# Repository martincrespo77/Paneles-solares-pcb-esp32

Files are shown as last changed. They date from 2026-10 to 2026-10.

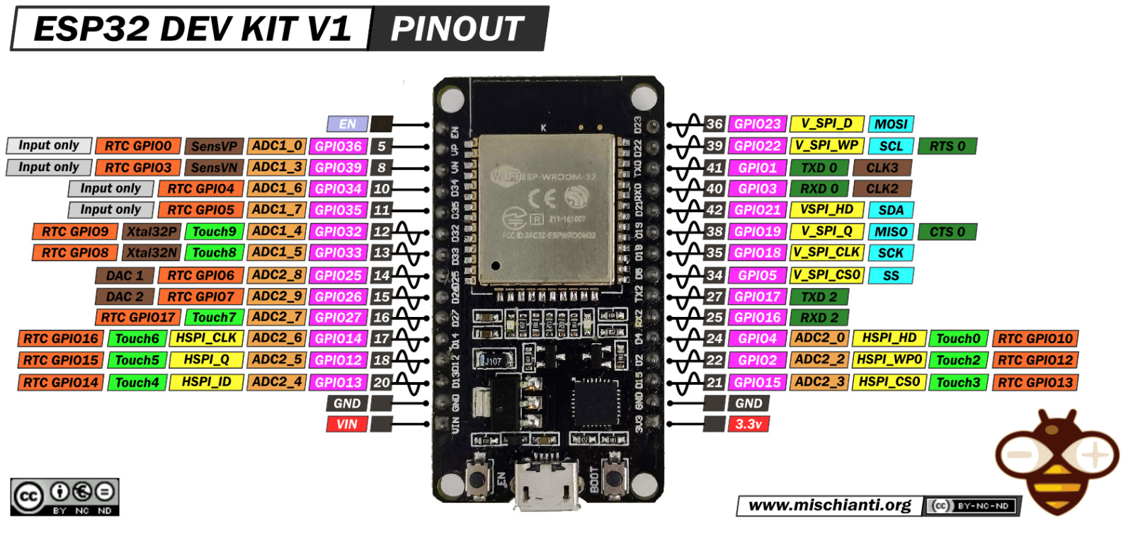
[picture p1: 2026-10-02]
Esp32 para diagrama digital.jpeg

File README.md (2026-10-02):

# Seguidor Solar (Sun Tracker) de 2 Ejes con ESP32

**Cátedra:** Técnicas Digitales 2 — FIE (Facultad de Ingeniería del Ejército)  
**Estado:** Firmware base implementado y verificado en PlatformIO  

---

## 1. Descripción del Proyecto

Este proyecto consiste en la **migración y modernización del sistema de control del Seguidor Solar (Sun Tracker) de dos ejes** (Azimut y Elevación). 

El sistema original estaba implementado en código de bajo nivel en C para un microcontrolador AVR (**ATmega168/328**) utilizando el puente H L298HN y un demultiplexor CD4053 (referencia: informe técnico `UNDEFI 263` en `INFORMACION VIEJA/`).

En esta etapa se porta el núcleo de control hacia un microcontrolador moderno **ESP32 DOIT DevKit V1 (30 pines)** bajo el framework PlatformIO / Arduino C++, conservando las ecuaciones físicas del lazo de control, la calibración PI probada y la robustez del accionamiento.

---

## 2. Arquitectura de Control

```
                 [ 4 LDRs en cruz: F0, F1, F2, F3 ]
                                |
                                v
               [ ADC1 del ESP32 (4 canales a 10 bits) ]
                                |
                                v
                [ Cálculo de error (Azimut / Elevación) ]
                                |
                                v
             [ Control PI por eje con Anti-Windup y Deadband ]
                                |
                                v
            [ Generación PWM (LEDC 1 kHz) + Señales de Sentido ]
                                |
                                v
                [ Etapa de Potencia: Puente H Doble ]
                                |
                                v
              [ Motores DC Azimut (P1) y Elevación (P2) ]
```

### Algoritmo y Ley de Control

1. **Lectura ADC:** Lee los 4 sensores LDR sobre el ADC1 (evitando conflictos de Wi-Fi), aplicando promediado de 8 muestras y reescalado de 12 a 10 bits (`0..1023`) para mantener compatibilidad con las constantes legadas.
2. **Cálculo de Error:**
   - Elevación: `Error_El = (F2 + F3 - F0 - F1) / 2`
   - Azimut: `Error_Az = (F1 + F3 - F0 - F2) / 2`
3. **Controlador PI Discreto:**
   - Ganancias: $K_p = 5.0$, $K_i = 0.1$, $K_d = 0.0$
   - Límite Anti-Windup: Clamping del integrador a $\pm 400.0$
   - Zona Muerta (`DEAD_BAND = 5`): Evita oscilaciones por jitter o ruido eléctrico cuando el panel está orientado.
4. **Modulación PWM:** Canales LEDC a 1 kHz con 10 bits de resolución (`PWM_MAX = 1023`).

---

## 3. Mapeo de Pines (ESP32 DevKit V1)

| Señal | Pin ESP32 | Función | Destino en Hardware |
|---|:---:|---|---|
| **FOTO0** | `GPIO36` (VP) | Entrada ADC1 Ch0 | LDR 0 (Superior izquierdo) |
| **FOTO1** | `GPIO39` (VN) | Entrada ADC1 Ch3 | LDR 1 (Superior derecho) |
| **FOTO2** | `GPIO34` | Entrada ADC1 Ch6 | LDR 2 (Inferior izquierdo) |
| **FOTO3** | `GPIO35` | Entrada ADC1 Ch7 | LDR 3 (Inferior derecho) |
| **PWM_AZ** | `GPIO25` | Salida PWM (LEDC CH0) | ENA / Entrada PWM motor Azimut |
| **PWM_EL** | `GPIO26` | Salida PWM (LEDC CH1) | ENB / Entrada PWM motor Elevación |
| **DIR_AZ** | `GPIO27` | Salida Digital | IN_A / Sentido de giro Azimut |
| **DIR_EL** | `GPIO14` | Salida Digital | IN_B / Sentido de giro Elevación |
| **STATUS** | `GPIO2` | Salida Digital | LED onboard (Heartbeat / Fault) |

---

## 4. Estructura del Repositorio

*   [`src/main_tracker.cpp`](src/main_tracker.cpp): Firmware principal en C++ para la ESP32.
*   [`platformio.ini`](platformio.ini): Configuración de compilación para ESP32 DOIT DevKit V1.
*   [`Kicad/Control de panel/`](Kicad/Control%20de%20panel/): Proyecto de esquemático y PCB en KiCad adaptado para zócalo ESP32 DevKit V1 30 pines.
*   [`docs/`](docs/):
    *   [`CONTEXTO_TD2_SUN_TRACKER.md`](docs/CONTEXTO_TD2_SUN_TRACKER.md): Contexto técnico detallado y trazabilidad del proyecto.
    *   [`DOCUMENTO_TECNICO_TD2_SUN_TRACKER.md`](docs/DOCUMENTO_TECNICO_TD2_SUN_TRACKER.md): Especificación técnica formal y modelo matemático.
    *   [`PLANMODE_ARMADO_TD2.md`](docs/PLANMODE_ARMADO_TD2.md): Guía de validación y puesta en marcha en banco por etapas.
*   [`INFORMACION VIEJA/`](INFORMACION%20VIEJA/): Archivos históricos de referencia (informe final UNDEFI 263, esquemático analógico y firmware AVR en C).

---

## 5. Compilación y Carga

Con [PlatformIO](https://platformio.org/) instalado:

```powershell
# Compilar el firmware del Sun Tracker
pio run -e tracker

# Cargar a la placa ESP32 (ajustar puerto COM en platformio.ini si difiere)
pio run -e tracker -t upload

# Abrir el monitor serie (115200 baud)
pio device monitor -e tracker
```

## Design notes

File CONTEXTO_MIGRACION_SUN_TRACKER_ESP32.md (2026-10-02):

# Contexto tecnico del proyecto Sun Tracker y migracion a ESP32

Fecha de analisis: 2026-05-22

Este documento resume lo entendido del proyecto actual, del firmware viejo, del circuito general del informe y del objetivo de migracion. No es todavia un plan de implementacion. Sirve para validar si estamos hablando del mismo problema antes de pedir un plan detallado.

## 1. Resumen corto

El repositorio contiene dos lineas de trabajo relacionadas:

1. **Sun Tracker viejo**: sistema de seguimiento solar de dos ejes, azimut y elevacion, basado en un microcontrolador AVR ATmega168/328, cuatro sensores LDR, control PI/PID discreto y un puente H L298 para mover dos motores DC con reductor.
2. **Trabajo nuevo con ESP32**: primer material para usar ESP32 con MicroPython, medicion/telemetria de variables solares y transmision optica por laser. Ese codigo nuevo todavia no controla motores.

El objetivo actual es conservar la logica funcional del Sun Tracker viejo, migrarla a una **ESP32 programada en MicroPython/Python**, y mover los motores mediante un **puente H**. El enfoque correcto es portar primero el control de seguimiento y despues integrarlo con la telemetria optica, no mezclar todo desde el primer paso.

## 2. Archivos relevantes encontrados

### Material viejo

- `INFORMACION VIEJA-20260522T124344Z-3-001/INFORMACION VIEJA/UNDEFI 263 - Informe Final.pdf`
  - Informe tecnico del Sun Tracker.
  - Explica objetivo, mecanica, sensores, motores, puente H, PID discreto y circuito.

- `INFORMACION VIEJA-20260522T124344Z-3-001/INFORMACION VIEJA/Circuito Eléctrico/Sun_seeker.PDF`
  - Esquematico electronico general.
  - Incluye ATmega168/328, L298HN, CD4053, LM7805, sensores LDR y conectores de motores.

- `INFORMACION VIEJA-20260522T124344Z-3-001/INFORMACION VIEJA/Firmware/Sun Tracker/Sun Tracker/popo/popo/`
  - Firmware en C para AVR.
  - Archivos principales: `popo.c`, `ADC.c`, `Leo_Fotos.c`, `PWM.c`, `PID_Elev.c`, `PID_Azim.c`, `PORT.c`, `Constantes.c`, `USART.c`, `Def.h`.

### Material nuevo

- `Info general.md`
  - Define un sistema de telemetria solar por enlace optico FSO usando dos ESP32.
  - Usa sensor de energia, laser, fototransistor/comparador y tramas JSON con CRC.

- `Código de Ejecución en MicroPython (Nodo Transmisor).py`
  - Script MicroPython inicial para ESP32.
  - Lee valores simulados de energia, arma JSON, calcula CRC32 y transmite por UART hacia laser.
  - No controla LDR ni motores.

- `Diagrama de flujo.txt`
  - Flujo del nodo transmisor de telemetria: inicializar perifericos, leer sensor, acumular potencia, generar historico, armar JSON, calcular CRC y transmitir.

- `Proyecto FINAL Optoelectronica/`
  - Carpeta encontrada vacia.

- `Proyecto FINAL Tecnicas digitales 2/`
  - Carpeta encontrada vacia.

## 3. Que hace el proyecto viejo

El proyecto viejo es un **seguidor solar de doble eje**. Su objetivo es orientar un panel fotovoltaico hacia el Sol para mejorar la captacion de energia.

Segun el informe, el sistema tiene:

- Panel solar fotovoltaico Solartec KS45TA de 45 Wp.
- Movimiento en dos ejes:
  - **Azimut**.
  - **Elevacion**.
- Dos motores de corriente continua con reductor, modelo IGNIS MR08D-012004-4.0, con motor Mabuchi RS-385PH-2085.
- Sensado de luz mediante cuatro LDR ubicados en un discriminador de sombra en forma de cruz.
- Control digital ejecutado en un microcontrolador AVR.
- Accionamiento de motores mediante puente H L298.

La idea de control es tradicional y correcta para este tipo de prototipo: comparar luz recibida en cuatro cuadrantes, calcular error por eje, y mover cada motor hasta minimizar el error.

## 4. Sensores y calculo de error

El sensor optico viejo usa cuatro LDR:

- `FOTO0`
- `FOTO1`
- `FOTO2`
- `FOTO3`

Estan separados por una barrera horizontal y una barrera vertical. Esa cruz genera sombras cuando el panel no esta orientado correctamente.

El firmware viejo lee los cuatro sensores por ADC:

- `ADC0 -> FOTO0`
- `ADC1 -> FOTO1`
- `ADC2 -> FOTO2`
- `ADC3 -> FOTO3`

La logica de error implementada en C es:

```c
Error_El = (adc_dato_2 + adc_dato_3 - adc_dato_0 - adc_dato_1) / 2;
Error_Az = (adc_dato_1 + adc_dato_3 - adc_dato_0 - adc_dato_2) / 2;
```

Interpretacion:

- Elevacion compara el promedio inferior/superior, segun como esten montados los LDR.
- Azimut compara el promedio derecho/izquierdo.
- Si el error es positivo o negativo, cambia el sentido del motor.
- Si el error tiende a cero, el sistema esta alineado.

Esto hay que conservar en la migracion. Si se invierte fisicamente un motor o se cambia el orden de LDR, no se cambia la teoria: se ajusta el signo o el mapeo.

## 5. Circuito viejo segun informe y esquematico

El circuito viejo se organiza asi:

```text
4 LDR -> ADC0..ADC3 del ATmega -> calculo de error -> PI/PID discreto
      -> PWM + bits de sentido -> CD4053 / L298 -> motores DC de azimut y elevacion
```

Componentes principales:

- **U1: ATmega168/328**
  - El informe habla de ATmega328.
  - El proyecto Atmel Studio figura configurado como ATmega168.
  - El comentario del firmware dice que el codigo es compatible con ATmega328 y ATmega168.

- **U2: L298HN**
  - Puente H doble.
  - Maneja dos motores DC.
  - Un puente para azimut.
  - Otro puente para elevacion.

- **U3: CD4053BCN**
  - Multiplexor/demultiplexor analogico usado para direccionar senales de control hacia el L298.

- **U4: LM7805**
  - Regulador lineal para alimentar la electronica de control a 5 V.

- **D1 a D8: FR107**
  - Diodos rapidos de rueda libre para proteger frente a energia inductiva de los motores.

- **Y1: cristal de 16 MHz**
  - El esquematico muestra 16 MHz.

- **R2, R3, R4, R5: 4k7**
  - Resistencias asociadas a los sensores LDR.

- **P1**
  - Motor de acimut.

- **P2**
  - Motor de elevacion.

- **P3**
  - Conector de sensores: `FOTO0`, `FOTO1`, `FOTO2`, `FOTO3` y alimentacion.

- **P4**
  - Entrada de alimentacion rotulada como `9Vcc` en el esquematico.
  - El informe menciona bateria pequena de `12Vcc`. Este punto hay que verificar fisicamente.

## 6. Pines y senales del firmware viejo

El firmware usa principalmente el puerto B del AVR:

| Funcion | AVR | Uso |
|---|---:|---|
| `PB0` | salida | bandera/debug para medir tiempos |
| `PB1 / OC1A` | salida PWM | PWM de azimut (`PWMA`) |
| `PB2 / OC1B` | salida PWM | PWM de elevacion (`PWME`) |
| `PB4` | salida digital | sentido de azimut (`SENTA`) |
| `PB5` | salida digital | sentido de elevacion (`SENTE`) |

El Timer1 se configura en Fast PWM de 10 bits. Por eso el PWM viejo trabaja en rango:

```text
0..1023
```

El codigo limita cada salida PWM a ese rango antes de escribir:

```c
OCR1A = PWM_Az; // azimut
OCR1B = PWM_El; // elevacion
```

## 7. Firmware viejo en C

El punto de entrada es `popo.c`.

Flujo principal:

```text
Inicializar constantes
Inicializar puertos
Inicializar ADC
Inicializar USART
Inicializar PWM

while(1):
    levantar bandera PB0
    leer FOTO0..FOTO3
    bajar bandera PB0
    ejecutar control de elevacion
    ejecutar control de azimut
```

Modulos:

- `PORT.c`
  - Configura pines del puerto B como salida.
  - El puerto D queda como entrada.

- `ADC.c`
  - Configura ADC con referencia externa AREF.
  - Modo single conversion.
  - Resultado de 10 bits.

- `Leo_Fotos.c`
  - Lee secuencialmente ADC0, ADC1, ADC2 y ADC3.
  - Arma valores de 10 bits en `adc_dato_0` a `adc_dato_3`.

- `PWM.c`
  - Configura Timer1 en Fast PWM de 10 bits.
  - Usa salidas OC1A y OC1B.

- `PID_Elev.c`
  - Calcula error de elevacion.
  - Integra el error.
  - Aplica anti-windup.
  - Calcula PWM.
  - Define sentido por `PB5`.
  - Escribe `OCR1B`.

- `PID_Azim.c`
  - Calcula error de azimut.
  - Integra el error.
  - Aplica anti-windup.
  - Calcula PWM.
  - Define sentido por `PB4`.
  - Escribe `OCR1A`.

- `Constantes.c`
  - Inicializa ganancias y variables.

Constantes usadas por el firmware C:

```c
Kp_El = 5.0;
Ki_El = 0.1;
Kd_El = 0.0;

Kp_Az = 5.0;
Ki_Az = 0.1;
Kd_Az = 0.0;

Reset_aw = 400.0;
```

Punto importante: aunque los archivos se llaman `PID`, el codigo activo implementa en la practica un **PI**, porque no usa el termino derivativo. `Kd` existe como variable, pero no participa en la ley de control.

## 8. Diferencias y dudas tecnicas detectadas

Hay varias diferencias que no conviene ignorar:

1. **ATmega168 vs ATmega328**
   - El informe habla de ATmega328.
   - El esquematico dice ATmega168/328.
   - El `.cproj` esta configurado para ATmega168.
   - El comentario de `popo.c` habla de ATmel 328 compatible con 168.
   - Para la migracion no afecta demasiado, pero para documentar el original hay que decirlo como esta: familia ATmega168/328.

2. **9 Vcc vs 12 Vcc**
   - El esquematico rotula una entrada como `9Vcc`.
   - El informe habla de bateria de `12Vcc`.
   - El L298 y los motores se modelan con 12 V.
   - Antes de cablear la ESP32 hay que medir o confirmar la alimentacion real.

3. **Cristal y USART**
   - El esquematico muestra cristal de 16 MHz.
   - `USART.c` comenta "57600 baud with 20 MHz osc" y usa `UBRR0L = 0x15`.
   - Si el reloj real es 16 MHz, ese valor no da 57600 exactos en modo normal.
   - La USART parece secundaria o de depuracion, no es central para el control.

4. **PID teorico vs PI implementado**
   - El informe desarrolla PID discreto.
   - El codigo final usa Kd = 0 y no calcula derivada.
   - Para migrar, lo conservador es portar primero el PI real que funcionaba.

5. **L298**
   - Es tradicional, robusto y aparece en el circuito.
   - Tambien es viejo e ineficiente frente a drivers modernos.
   - Si el objetivo academico es respetar el informe, se puede usar L298.
   - Si el objetivo es eficiencia electrica, convendria evaluar otro puente H, pero eso ya es decision de diseno.

## 9. Codigo nuevo en MicroPython

El archivo `Código de Ejecución en MicroPython (Nodo Transmisor).py` es un primer nodo de telemetria.

Hace esto:

1. Configura I2C para un sensor de energia.
2. Configura UART2 para transmitir por laser.
3. Simula lectura de voltaje, corriente y potencia.
4. Acumula potencia.
5. Mantiene un historico de 24 bloques horarios.
6. Arma un JSON.
7. Calcula CRC32.
8. Transmite una trama por UART:

```text
[JSON|CRC32]\n
```

Ese codigo sirve para el proyecto de optoelectronica/telemetria. No reemplaza todavia al firmware del Sun Tracker.

## 10. Objetivo de migracion a ESP32

La migracion principal deberia apuntar a esto:

```text
4 LDR -> ADC de ESP32 -> control PI/PID en MicroPython
      -> PWM + direccion -> puente H -> motores de azimut/elevacion
```

La ESP32 reemplaza al ATmega como unidad de control. El puente H reemplaza o conserva la etapa de potencia. Los motores no se conectan jamas directo a la ESP32.

Aspectos minimos de la migracion:

- Leer cuatro entradas analogicas de la ESP32.
- Tener en cuenta que el ADC de ESP32 no se comporta igual que el ADC AVR:
  - AVR: 10 bits, referencia controlada.
  - ESP32: normalmente 12 bits, no lineal, requiere atenuacion y calibracion practica.
- Portar las ecuaciones de error.
- Portar la ley PI actual:
  - proporcional
  - integral
  - anti-windup
  - saturacion de PWM
  - seleccion de sentido
- Generar PWM con `machine.PWM`.
- Controlar pines digitales de direccion.
- Definir una zona muerta para evitar que el sistema tiemble cuando el error sea pequeno.
- Agregar limites de seguridad:
  - fin de carrera, si existen
  - corte por corriente, si el driver lo permite
  - timeout de movimiento
  - parada por sensores invalidos
  - parada manual o modo seguro

## 11. Propuesta de separacion entre ambos proyectos

Para no ensuciar el diseno, conviene separar los proyectos asi:

### Proyecto A: Tecnicas Digitales 2

Tema central:

```text
Migracion del Sun Tracker viejo a ESP32 con MicroPython y puente H.
```

Responsabilidades:

- Lectura de LDR.
- Control de orientacion.
- Movimiento de dos motores.
- Driver de puente H.
- Seguridad electrica y mecanica.
- Validacion con pruebas de banco.

Este proyecto debe nacer del firmware AVR viejo, porque ahi esta la logica de control que ya funcionaba.

### Proyecto B: Optoelectronica

Tema central:

```text
Telemetria optica de variables solares entre dos ESP32 usando laser.
```

Responsabilidades:

- Medicion de voltaje, corriente y potencia.
- Construccion de tramas.
- CRC.
- Transmision por laser.
- Recepcion por fototransistor/comparador.
- Validacion del enlace optico.

Este proyecto debe nacer del archivo MicroPython actual y de `Info general.md`.

### Relacion entre ambos

Ambos proyectos se conectan porque usan el mismo sistema fisico solar:

- El Sun Tracker orienta el panel.
- La telemetria mide o transmite informacion del panel.
- Ambos pueden usar ESP32.
- Ambos pueden compartir alimentacion y gabinete, pero no conviene que compartan responsabilidades al comienzo.

Lo correcto es que primero funcionen por separado:

1. Control de motores estable.
2. Telemetria optica estable.
3. Integracion final con interfaces claras.

## 12. Como iniciar el trabajo

### Inicio recomendado para el Proyecto A

1. Levantar una tabla exacta de pines ESP32.
2. Decidir puente H:
   - L298 si se respeta el circuito historico.
   - Otro driver si se prioriza eficiencia.
3. Medir tension real de motores y corriente maxima.
4. Cablear una sola etapa de motor en banco, sin el panel.
5. Probar PWM y direccion manual.
6. Leer los cuatro LDR en MicroPython.
7. Verificar que el orden de sensores coincida con `FOTO0..FOTO3`.
8. Portar el calculo de error.
9. Portar PI de un eje.
10. Repetir para el segundo eje.
11. Agregar zona muerta, limites y parada segura.
12. Montar en la mecanica real.

### Inicio recomendado para el Proyecto B

1. Definir si se mide lado DC del panel o lado AC del inversor.
2. Elegir sensor:
   - INA226 para DC.
   - PZEM-004T para AC.
3. Reemplazar los valores simulados del script MicroPython por lectura real.
4. Probar UART local por cable antes del laser.
5. Probar laser con distancia corta.
6. Validar recepcion y CRC.
7. Agregar reintentos o descarte de tramas corruptas.
8. Registrar historico de datos.

## 13. Riesgos tecnicos

- La ESP32 trabaja a 3.3 V logicos. Si se reutiliza L298/CD4053 alimentado a 5 V, hay que verificar compatibilidad de niveles.
- El ADC de ESP32 necesita calibracion. No hay que asumir que leer `0..4095` equivale linealmente a luz util.
- Los motores generan ruido electrico. Hay que separar masa de potencia y logica con criterio, usar capacitores y cableado corto.
- El L298 disipa potencia. Puede calentar si la corriente del motor se acerca al limite.
- Sin finales de carrera se puede forzar la mecanica.
- MicroPython no es tiempo real duro. Para este sistema puede alcanzar porque el seguimiento solar es lento, pero los callbacks de timer no deben hacer calculos pesados ni asignar memoria.
- Si se integra laser y motores en la misma ESP32, el ruido de motores puede degradar la comunicacion optica.

## 14. Decision tecnica inicial

Mi lectura conservadora es esta:

1. No hay que empezar escribiendo un sistema nuevo desde cero.
2. Hay que portar primero el comportamiento real del AVR:
   - cuatro ADC
   - dos errores
   - PI por eje
   - PWM absoluto
   - bit de direccion
3. El puente H debe tratarse como etapa de potencia separada.
4. La telemetria FSO debe quedar como segundo modulo, no mezclada con el control de movimiento.
5. Las carpetas `Proyecto FINAL Optoelectronica` y `Proyecto FINAL Tecnicas digitales 2` deberian usarse para separar formalmente ambos entregables.

## 15. Pendientes para confirmar antes del plan detallado

Antes de pedir un plan completo a Claude o a cualquier agente de planificacion, hay que confirmar:

1. Que puente H se usara realmente: L298/L298N, BTS7960, TB6612FNG u otro.
2. Tension real de motores: 9 V, 12 V u otra.
3. Corriente de arranque o bloqueo de cada motor.
4. Modelo exacto de ESP32.
5. Si se mantendran los cuatro LDR originales.
6. Si existen finales de carrera fisicos.
7. Si el proyecto final exige MicroPython si o si, o si se acepta C/C++ con ESP-IDF/Arduino.
8. Si la telemetria optica va en la misma ESP32 que controla motores o en otra ESP32 separada.

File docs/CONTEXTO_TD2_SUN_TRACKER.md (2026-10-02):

# TD2 — Sun Tracker ESP32: Contexto del proyecto y plan de migracion

**Materia:** Tecnicas Digitales 2  
**Estado:** En desarrollo  
**Fecha de escritura:** 2026-06-09

---

## 0. Proposito de este documento

Registrar el estado de comprension del problema antes de pedir un plan de implementacion.
Si algo esta mal descrito aqui, hay que corregir este documento, no arrancar a codear.

---

## 1. Que hay que hacer (en dos palabras)

Tomar el **Sun Tracker de dos ejes que ya existe en C para AVR** y portarlo a una
**ESP32 programada en C++ con PlatformIO/Arduino**.

La logica de control PI, los sensores LDR, el puente H y los motores se conservan.
El microcontrolador cambia de ATmega168/328 a ESP32.

---

## 2. Que ya existe (material viejo)

Todo el material fuente esta en `INFORMACION VIEJA/INFORMACION VIEJA/`.

### Informe tecnico

`INFORMACION VIEJA/INFORMACION VIEJA/UNDEFI 263 - Informe Final.pdf`

Describe el sistema completo: objetivo, mecanica, sensores, motores, puente H,
control PI discreto y circuito electronico.

### Esquematico electronico

`INFORMACION VIEJA/INFORMACION VIEJA/Circuito Electrico/Sun_seeker.PDF`

Circuito con ATmega168/328, L298HN, CD4053BCN, LM7805, LDR (4x) y conectores de motores.

### Firmware AVR (fuente de referencia principal)

`INFORMACION VIEJA/INFORMACION VIEJA/Firmware/Sun Tracker.rar`

Proyecto Atmel Studio. Archivos clave:

| Archivo | Rol |
|---|---|
| `popo.c` | Punto de entrada, loop principal |
| `ADC.c` | Configuracion ADC de 10 bits, referencia externa |
| `Leo_Fotos.c` | Lectura secuencial de ADC0..ADC3 |
| `PWM.c` | Timer1 Fast PWM 10 bits, OC1A y OC1B |
| `PID_Elev.c` | Control PI de elevacion |
| `PID_Azim.c` | Control PI de azimut |
| `PORT.c` | Configuracion de pines |
| `Constantes.c` | Inicializacion de ganancias y variables |
| `USART.c` | UART de debug (secundaria) |
| `Def.h` | Definiciones comunes |

---

## 3. Como funciona el sistema viejo

### Sensado de luz (4 LDR)

Cuatro LDR colocados en un discriminador de sombra en forma de cruz:

```
    [FOTO0]  [FOTO1]
    ----|--------|----   <- barrera horizontal
    [FOTO2]  [FOTO3]
```

Conectados a ADC0..ADC3 del AVR (10 bits, referencia externa AREF, single conversion).

### Calculo de error

```c
// Error de elevacion (eje vertical)
Error_El = (adc_dato_2 + adc_dato_3 - adc_dato_0 - adc_dato_1) / 2;

// Error de azimut (eje horizontal)
Error_Az = (adc_dato_1 + adc_dato_3 - adc_dato_0 - adc_dato_2) / 2;
```

Cuando el panel esta bien orientado, los cuatro LDR reciben la misma luz y el
error tiende a cero.

### Ley de control (PI, no PID)

Aunque los archivos se llaman `PID_*.c`, el codigo activo implementa un **PI**.
`Kd` existe como variable pero no participa.

Constantes del firmware viejo:

```c
Kp_El = 5.0;   Ki_El = 0.1;   Kd_El = 0.0;   // elevacion
Kp_Az = 5.0;   Ki_Az = 0.1;   Kd_Az = 0.0;   // azimut

Reset_aw = 400.0;  // limite anti-windup (valor absoluto del integrador)
```

Salida del PI para cada eje:

```
integrador += error * dt          // acumulacion
if |integrador| > Reset_aw:       // anti-windup por clamping
    integrador = signo * Reset_aw
pwm = Kp * error + Ki * integrador
pwm = clamp(pwm, 0, 1023)         // saturacion (10 bits)
sentido = (pwm_neto > 0) ? 1 : 0  // bit de direccion
OCR1A o OCR1B = |pwm|             // escritura Timer1
```

### Pines del AVR (referencia)

| AVR pin | Funcion | Nombre en firmware |
|---|---|---|
| `PB0` | bandera debug (osciloscopio) | — |
| `PB1 / OC1A` | PWM azimut | `PWMA` |
| `PB2 / OC1B` | PWM elevacion | `PWME` |
| `PB4` | sentido azimut | `SENTA` |
| `PB5` | sentido elevacion | `SENTE` |
| `ADC0` | FOTO0 | `adc_dato_0` |
| `ADC1` | FOTO1 | `adc_dato_1` |
| `ADC2` | FOTO2 | `adc_dato_2` |
| `ADC3` | FOTO3 | `adc_dato_3` |

---

## 4. Circuito electronico (hardware viejo, segun esquematico)

```
4 LDR -> ADC0..ADC3 del ATmega
      -> calculo de error
      -> PI por eje
      -> PWM + bit de sentido
      -> CD4053BCN (multiplexor analogico de control)
      -> L298HN (puente H doble)
      -> 2 motores DC con reductor (azimut y elevacion)
```

Componentes principales:

| Ref | Parte | Funcion |
|---|---|---|
| U1 | ATmega168/328 | Controlador digital |
| U2 | L298HN | Puente H doble (dos motores) |
| U3 | CD4053BCN | Multiplexor/demux analogico de senales de control |
| U4 | LM7805 | Regulador 5 V para la logica |
| D1-D8 | FR107 | Diodos de rueda libre (proteccion inductiva) |
| Y1 | Cristal 16 MHz | Reloj del AVR |
| R2-R5 | 4k7 | Resistencias de carga para los LDR |
| P1 | Motor azimut | IGNIS MR08D-012004-4.0 / Mabuchi RS-385PH-2085 |
| P2 | Motor elevacion | Idem |
| P3 | Conector sensores | FOTO0..FOTO3 + alimentacion |
| P4 | Alimentacion | 9 Vcc segun esquema (informe dice 12 Vcc: VERIFICAR) |

---

## 5. Migracion a ESP32 — lo que hay que construir

### Diagrama objetivo

```
4 LDR (4k7 pull-down)
   |
ADC1 del ESP32 (12 bits, canales 34/35/36/39)
   |
calculo de error (misma formula del AVR)
   |
PI por eje (mismas constantes de partida, ajustar en banco)
   |
LEDC PWM 12 bits + GPIO de sentido
   |
Puente H (L298N o equivalente)
   |
Motor azimut + Motor elevacion
```

### Pines propuestos para ESP32 DevKit

| ESP32 GPIO | Funcion | Notas |
|---|---|---|
| GPIO36 (VP) | FOTO0 (LDR0) | ADC1 ch0, solo entrada |
| GPIO39 (VN) | FOTO1 (LDR1) | ADC1 ch3, solo entrada |
| GPIO34 | FOTO2 (LDR2) | ADC1 ch6, solo entrada |
| GPIO35 | FOTO3 (LDR3) | ADC1 ch7, solo entrada |
| GPIO25 | PWM azimut | LEDC, salida analogica posible |
| GPIO26 | PWM elevacion | LEDC |
| GPIO27 | Sentido azimut | GPIO digital |
| GPIO14 | Sentido elevacion | GPIO digital |
| GPIO2 | LED estado (integrado) | debug/heartbeat |
| GPIO0 | — | NO usar (boot) |

> **Nota ADC ESP32:** El ADC del ESP32 no es lineal. Requiere atenuacion
> `ADC_11db` (0..3.3 V) y calibracion practica. El rango util real es
> aprox. 150..3900 cuentas de las 4096. Tener en cuenta al escalar el error.

> **Nota niveles logicos:** El ESP32 trabaja a 3.3 V logicos. Si se reutiliza
> el L298 o el CD4053 alimentados a 5 V, verificar compatibilidad de entradas.
> El L298 acepta niveles de 3.3 V en sus entradas de control.

### Estructura del firmware nuevo (`src/main_tracker.cpp`)

Modulos a implementar (en orden de desarrollo):

1. **Lectura ADC** — leer GPIO36/39/34/35, atenuar, calibrar offset
2. **Calculo de error** — portar las dos formulas directamente del C viejo
3. **PI por eje** — portar `PID_Elev.c` y `PID_Azim.c`, escalar a 12 bits
4. **PWM LEDC** — `ledcSetup` + `ledcWrite` para azimut y elevacion
5. **Sentido** — `digitalWrite` segun signo del PI
6. **Zona muerta** — `if (abs(error) < DEAD_BAND) { parar motor }` para evitar oscilacion
7. **Seguridad** — timeout por sensor invalido, parada manual por Serial

---

## 6. Diferencias tecnicas detectadas entre AVR y ESP32

| Aspecto | ATmega168/328 | ESP32 | Accion |
|---|---|---|---|
| ADC bits | 10 bits (0..1023) | 12 bits (0..4095) | Escalar error y anti-windup |
| ADC linealidad | Buena con AREF | No lineal, necesita calibracion | Agregar tabla o compensacion |
| PWM bits | 10 bits (0..1023) | 1..16 bits via LEDC | Usar 10 bits para conservar Kp/Ki |
| Logica | 5 V | 3.3 V | Verificar compatibilidad con L298 |
| Tiempo de loop | Timer por interrupcion (Timer0) | FreeRTOS / loop() de Arduino | Fijar `dt` real con `millis()` |
| USART debug | 57600 baud (dudoso a 16 MHz) | Serial normal a 115200 | Usar Serial ESP32 normalmente |

---

## 7. Pendientes antes de implementar

Confirmar fisicamente antes de escribir una sola linea de codigo:

- [ ] Que puente H se usara: L298N de modulo, BTS7960, TB6612FNG u otro.
- [ ] Tension real de alimentacion de motores: 9 V o 12 V (el esquema dice 9 V, el informe dice 12 V).
- [ ] Corriente de arranque o bloqueo de cada motor (para no quemar el driver).
- [ ] Si existen finales de carrera fisicos o no.
- [ ] Si se conservan los cuatro LDR originales y su disposicion.
- [ ] Modelo exacto de ESP32 disponible (DevKit V1, WROOM-32 30p u otro).
- [ ] Si el proyecto exige MicroPython o se acepta C++ con Arduino/PlatformIO.

---

## 8. Riesgos tecnicos conocidos

- **Ruido electrico de motores:** separar masa de potencia y logica. Capacitores en
  paralelo a los motores (100 nF ceramico + 100 uF electrolitico).
- **ADC ESP32 + motores en mismo PCB:** el ruido de conmutacion del puente H puede
  degradar las lecturas ADC. Filtros RC en las entradas de los LDR.
- **MicroPython no es tiempo real duro:** para seguimiento solar (movimientos lentos)
  puede alcanzar, pero no sirve si se necesitan interrupciones criticas.
- **Sin finales de carrera:** si el motor fuerza el limite mecanico, puede romper la
  estructura. Agregar corte por corriente o sensores de fin de recorrido.
- **L298 disipacion:** el L298 cae 2 V internos. Con 12 V de alimentacion, los motores
  reciben ~10 V reales. Considerar ventilacion si la corriente supera 1 A.

---

## 9. Relacion con el proyecto de Optoelectronica (FINALIZADO)

El proyecto de Optoelectronica es independiente y esta cerrado.

Usa los mismos ESP32 pero para un sistema de comunicacion optica laser FSO.
La telemetria que transmite ese sistema (`TelemetryData`) incluye campos de
este tracker (`F0..F3`, `errAz`, `errEl`, `motAz`, `motEl`) como datos **simulados**.

Cuando el tracker TD2 este operativo, esa simulacion se puede reemplazar por
lecturas reales, pero es una decision de integracion futura.

Los dos proyectos **no comparten codigo fuente en la misma compilacion**.
Cada uno tiene su propio entorno en `platformio.ini`.

---

## 10. Estado actual del repo para TD2

| Elemento | Estado |
|---|---|
| `INFORMACION VIEJA/` (firmware AVR fuente) | Existe localmente, en `.rar` |
| `src/main_tracker.cpp` | **No existe todavia** |
| `docs/CONTEXTO_TD2_SUN_TRACKER.md` | Este archivo |
| `platformio.ini` env:tracker | Definido (apunta a `main_tracker.cpp`) |
| Control PI portado | **Pendiente** |
| Esquema de pines ESP32 | Propuesto (tabla seccion 5), sin confirmar fisicamente |

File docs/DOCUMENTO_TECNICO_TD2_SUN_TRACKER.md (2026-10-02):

# Documento Tecnico TD2 - Migracion Sun Tracker a ESP32

Estado: borrador tecnico vigente para Tecnicas Digitales 2.  
Fecha: 2026-06-09.

## 1. Alcance y separacion de proyectos

Este documento cubre solo TD2: migracion del controlador del Sun Tracker viejo
(ATmega168/328) hacia ESP32.

Optoelectronica se considera finalizado y queda separado del alcance actual.
No se usa como base de diseno de control de motores.

## 2. Que informacion SI existe en la carpeta vieja

Fuente local verificada:

- `INFORMACION VIEJA/INFORMACION VIEJA/UNDEFI 263 - Informe Final.pdf`
- `INFORMACION VIEJA/INFORMACION VIEJA/Circuito Eléctrico/Sun_seeker.PDF`
- `INFORMACION VIEJA/INFORMACION VIEJA/Firmware/Sun Tracker/Sun Tracker/popo/popo/*.c`

Datos recuperables de forma confiable:

- Algoritmo de control PI por eje.
- Ecuaciones de error para azimut y elevacion.
- Constantes iniciales: `Kp=5.0`, `Ki=0.1`, `Kd=0.0`, `Reset_aw=400.0`.
- PWM de 10 bits (0..1023) y direccion por bit de sentido.
- Lectura de 4 sensores por ADC (canales 0..3 en AVR).

## 3. Que datos SIGUEN faltando para construccion final

No aparecen explicitamente en el firmware viejo:

- Definicion final del puente H a usar en el nuevo armado (si se conserva L298 o no).
- Tension real medida de motores en la maqueta actual (9 V o 12 V efectivos).
- Corriente de arranque/bloqueo de cada motor.
- Confirmacion de finales de carrera fisicos.
- Criterio de protecciones (fusible, corte por sobrecorriente, TVS, etc.).

## 4. Arquitectura objetivo (simulada para ESP32 + periferia)

Se modela una arquitectura de referencia para avanzar aun sin cerrar los faltantes.

```mermaid
flowchart LR
  subgraph SENSORES[Entrada de sensores]
    L0[LDR F0]
    L1[LDR F1]
    L2[LDR F2]
    L3[LDR F3]
  end

  subgraph ESP32[Controlador ESP32]
    ADC[ADC1 x4 canales]
    ERR[Calculo de error Az/El]
    PI[Control PI por eje]
    PWM[LEDC PWM x2 + DIR x2]
    SAFE[Supervision y seguridad]
  end

  subgraph POTENCIA[Etapa de potencia externa]
    HBRIDGE[Puente H doble]
    MA[Motor Azimut]
    ME[Motor Elevacion]
  end

  L0 --> ADC
  L1 --> ADC
  L2 --> ADC
  L3 --> ADC
  ADC --> ERR --> PI --> PWM --> HBRIDGE
  SAFE --> PI
  HBRIDGE --> MA
  HBRIDGE --> ME
```

## 5. Diagrama de flujo funcional

```mermaid
flowchart TD
  A[Boot ESP32] --> B[Init GPIO, ADC, LEDC, serial]
  B --> C[Leer F0-F1-F2-F3]
  C --> D[Filtrar y validar rangos ADC]
  D --> E[Calcular Error_Az y Error_El]
  E --> F[Actualizar integradores PI]
  F --> G[Anti-windup y saturaciones]
  G --> H[Determinar sentido y modulo PWM]
  H --> I[Aplicar PWM y DIR al puente H]
  I --> J{Fault?}
  J -- Si --> K[Parada segura + log serial]
  J -- No --> L[Esperar dt de control]
  K --> L
  L --> C
```

## 6. Mapa de componentes (modelo de trabajo)

| Bloque | Componente | Estado |
|---|---|---|
| Control | ESP32 DevKit (WROOM32) | Confirmado |
| Sensado | 4 x LDR + resistores de carga | Confirmado (por legado) |
| Potencia | Puente H doble | Pendiente eleccion final |
| Actuacion | 2 x motor DC (azimut/elevacion) | Confirmado |
| Alimentacion logica | 5V/3.3V regulada | Pendiente especificacion final |
| Seguridad | Fusible, proteccion corriente, E-stop | Pendiente |

## 7. Interfaz propuesta ESP32-periferia (simulada)

| Senal | Tipo | GPIO sugerido | Destino |
|---|---|---|---|
| F0 | ADC entrada | GPIO36 | LDR 0 |
| F1 | ADC entrada | GPIO39 | LDR 1 |
| F2 | ADC entrada | GPIO34 | LDR 2 |
| F3 | ADC entrada | GPIO35 | LDR 3 |
| PWM_AZ | PWM salida | GPIO25 | ENA / canal A puente H |
| PWM_EL | PWM salida | GPIO26 | ENB / canal B puente H |
| DIR_AZ | Digital salida | GPIO27 | IN_A sentido azimut |
| DIR_EL | Digital salida | GPIO14 | IN_B sentido elevacion |
| ESTADO | Digital salida | GPIO2 | LED debug |

Nota: son pines de referencia para desarrollo inicial. Se deben validar contra el
driver de potencia finalmente elegido.

## 8. Modelo matematico legado a preservar

Ecuaciones tomadas del firmware viejo:

$$
Error_{El} = \frac{(F2 + F3) - (F0 + F1)}{2}
$$

$$
Error_{Az} = \frac{(F1 + F3) - (F0 + F2)}{2}
$$

Ley PI discreta por eje:

$$
I_k = clamp(I_{k-1} + Error_k, -Reset_{aw}, Reset_{aw})
$$

$$
u_k = K_p\,Error_k + K_i\,I_k
$$

con saturacion de salida en el rango PWM permitido.

## 9. Criterio de avance aun con incertidumbre

Mientras faltan datos de hardware final, se puede avanzar en:

- Firmware base `main_tracker.cpp` con PI y HAL de pines desacoplado.
- Modo simulacion de sensores por serial para validar lazo de control.
- Pruebas con cargas de banco (sin mecanica) para PWM + sentido.

Se bloquea solamente:

- Ajuste final de ganancias en campo.
- Validacion termica/electrica de potencia.
- Definicion definitiva de limites de seguridad.

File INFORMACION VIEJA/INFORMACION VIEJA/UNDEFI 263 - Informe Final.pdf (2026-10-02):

PROGRAMA DE ACREDITACION Y FINANCIAMIENTO DE PROYECTOS DE INVESTIGACION

FORMULARIO PARA LA PRESENTACIÓN DEL INFORME FINAL 2018 / 2019

Marzo de 2021

### 1. DATOS GENERALES

Nº de Expediente UNDEF: 263/2018 (Resolución Rectoral UNDEF N° 309/18 del 14 de diciembre de 2018)

UNIDAD ACADEMICA: Facultad de Ingeniería del Ejército (FIE) (UNDEF)

TÍTULO DEL PROYECTO: Implementación de un sistema de control de seguimiento para la optimización del uso de la energía solar (Sun Tracker) (segunda etapa).

DIRECTOR DEL PROYECTO:

Nombre y Apellido: Mag. Ing. Patricio Enrique Rey DNI: 11.618.880
Teléfono/Fax: 4779-3382 / 15-4989-3404 E-mail: prey@fie.undef.edu.ar / prey@fi.uba.ar Monto asignado: $ 115.000

EQUIPO DE INVESTIGACIÓN:

Ing. Esp. Víctor Gustavo Nasini Mag. Ing. Esp. Carlos Bronzini
Mag. Ing. Ricardo Vecchio
Ing. Diego Alejandro Lazcano Colodrero

### 2. PERÍODO DE EJECUCION

Consignar fecha de inicio de las actividades y fecha de cierre de la ejecución de presupuesto. Indicar si continúa con actividades.

Fecha de inicio de actividades: 17 de noviembre de 2019
Fecha de finalización de actividades: 26 de marzo de 2021
Fecha de cierre de ejecución de presupuesto: 26 de marzo de 2021

El UNDEFI N° 263/18 fue prorrogado por la UNDEF hasta el 26 de marzo de 2021 (Ver Anexo 3). No continúa con actividades.

### 3. RESUMEN DE EJECUCIÓN DEL PROYECTO

El objetivo del UNDEFI N° 263/18 fue:
1) Implementar un sistema prototipo de control (o demostrador tecnológico) de orientación en dos ejes azimutal y elevación, para orientar un panel solar fotovoltaico hacia el sol y optimizar de esa manera la generación de energía eléctrica del mismo.
2) Implementar un sistema de orientación de paneles fotovoltaicos en satélites y sondas espaciales.

Este UNDEFI se inscribió dentro de la Línea de Investigación de Energías Renovables que se relaciona y complementa con otros que se desarrollan en la FIE; por ejemplo el PIDDEF 28/16 “Convertidor militarizado compacto para empleo en rango térmico de operaciones antárticas o de alta montaña”, que desarrolló un convertidor de DC-AC de 1,5 Kw, modular en onda sinusoidal.

También el UNDEFI se inscribió en el marco del Programa RenovAr (Programa de Energías Renovables - Argentinas 2016-2025) instrumento del que forma parte el Proyecto IRESUD (Interconexión a Red de Energía Solar Urbana Distribuida), el Proyecto PESE (Fideicomiso Programa Estudios del Sector Energético) y el Proyecto PERMER (Proyecto de Energías Renovables en Mercados Rurales), entre otros.
Además, la Ley Nº 27191 sobre Energías Renovables establece en su Artículo 5º como objetivo de la Segunda Etapa del "Régimen de Fomento Nacional para el Uso de Fuentes Renovables de Energía destinada a la Producción de Energía Eléctrica" instituido por la ley 26.190, con las modificaciones introducidas por la citada ley, “lograr una contribución de las fuentes renovables de energía hasta alcanzar el veinte por ciento (20%) del consumo de energía eléctrica nacional al 31 de diciembre de 2025.
Y más cerca en el tiempo, en su Artículo 1º se propone lograr una contribución de las fuentes de energía renovables hasta alcanzar el ocho por ciento (8%) del consumo de energía eléctrica nacional, al 31 de diciembre de 2017.
Los beneficiarios y usuarios directos e indirectos del Sun Tracker fueron:
a) Instalaciones de las Fuerzas Armadas a través de sus Guarniciones, Destacamentos, Brigadas, Batallones, Regimientos, etc. distribuidos en todo el país.
b) Instalaciones de la FIE.
c) Zonas rurales alejadas y poco pobladas (por ejemplo, pcia. de Salta).
d) Antártida Argentina y zonas fronterizas.

Durante la primera etapa del Proyecto (UNDEFI N° 307), se llevó a cabo el análisis y diseño de un sistema de control de seguimiento para la optimización de la energía solar.
Y se llegó a desarrollar un prototipo (entregable).

En el desarrollo del UNDEFI N° 263/18 realizado durante el año 2020 afectado por la pandemia, con todas las complicaciones y limitaciones asociadas a la situación de ASPO y DISPO, se llevaron a cabo periódicamente reuniones virtuales entre los integrantes del Equipo de investigación.
Y las actividades desarrolladas, sin acceso a los Laboratorios de la FIE, fueron las siguientes:
1) Investigación del panel solar, sensores, motores, componentes electrónicos y servicios especializados de provisión de partes mecánicas existentes en el mercado local.
2) Presupuestado de los componentes.
3) Implementación del sistema de sensado de luz solar.
4) Pruebas del panel solar bajo radiación solar y cargado con motores para evaluar su eficiencia.
5) Investigación y desarrollo de partes mecánicas de la estructura portante del panel solar y sistema de orientación con movimientos de elevación y azimuth. Por ser un prototipo, las partes mecánicas se realizaron mediante impresión 3D y no se tuvieron en cuenta el efecto de la UV (mecanizadas en el Laboratorio de Mecatrónica de la FIE).
6) Investigación, desarrollo e implementación del sistema de control mediante microcontroladores y amplificadores de potencia para la lectura de los sensores y actuación de los motores destinados para los ejes de movimientos de elevación y acimutal.

7) Desarrollo e implementación de un sistema mecánico portante del panel solar y su orientación mediante el uso de motores eléctricos en los dos ejes de movimientos de elevación y acimutal.
8) Integración de los sistemas mecánicos, eléctricos, electrónicos y ajustes correspondientes.
9) Implementación del control de seguimiento mediante la programación en tiempo real de los microcontroladores.
10) Ajustes y pruebas en campo.
11) Documentación de toda la información (en papel y digitalizada) surgida del Proyecto (en desarrollo).
12) Mecanizado, ajuste y armado de movimiento de panel solar en eje de elevación.
13) Impresión de las piezas 3D para el movimiento de azimuth.
14) Armado de la plaqueta electrónica de control y adecuación del programa de control de seguimiento en azimuth y elevación del panel solar al Sol. Este desarrollo fue resuelto en la Etapa 1, por lo que ahora se requiere su adecuación con el panel solar.
15) Realización de los ajustes finales.
16) Completamiento de toda la documentación del UNDEFI.
17) Elevación del Informe Técnico Final a la UNDEF (xx de marzo de 2021).
18) Entrega al Laboratorio de Energías Renovables y Eficiencia Energética de la FIE del demostrador tecnológico del Sun Tracker desarrollado durante el UNDEFI (xx de marzo de 2021).
19) Transferencia a la UNDEF de los fondos no utilizados (xx de marzo e 2021)

Una vista del demostrador tecnológico del Sun Tracker desarrollado es el siguiente:

Una imagen de la prueba de campo realizada con el demostrador tecnológico del Sun Tracker es la siguiente:

En el DVD que acompaña este Informe Final (Ver Anexo xxx) se puede apreciar un breve video grabado en fast motion que muestra el seguimiento del Sol que realiza el Sun Tracker.
En el Anexo 1 de este Informe Final se detalla el Legajo Técnico del UNDEFI N° 263/18.
En el DVD que se agrega como Anexo xxx del presente Informe Final se incluyen el video mencionado que muestra el funcionamiento del Sun Tracker y diversos archivos con información relacionada con su diseño, desarrollo y funcionamiento.

### 4. CUADRO DE LOS RESULTADOS ESPERADOS DEL PROYECTO

Indicar en las columnas correspondientes el Objetivo específico y las Actividades relacionadas a las que se refiere el resultado obtenido. Si correspondiese, los indicadores de los resultados obtenidos deben coincidir con los empleados en la presentación del proyecto para cada actividad. Repetir el formato para cada objetivo.

Objetivos específicos | Actividades | Resultado de actividad

Indicadores (cuantitativos y/o cualitativos) de los
resultados obtenidos

Investigación de sensores, motores, componentes electrónicos y servicios especializados de provisión de partes mecánicas existentes en el mercado local y de un seguidor solar | Estudio, relevamiento, análisis y comparación de la información obtenida | Primera 1. Especificaciones técnicas aproximación a las características del seguidor solar a desarrollar | básicas del equipamiento (100 %)
Implementación de sistema de sensado de luz solar. Adquisición de componentes | Elaboración de listado tentativo de componentes a adquirir | Especificaciones técnicas de componentes a adquirir. | Componentes adquiridos (100 %
Desarrollo e implementación de sistema de control mediante microcontroladores y amplificadores de potencia para la lectura de los sensores y actuación de los motores destinados para los ejes de movimientos acimutal y de elevación. | Diseño e implementación de todo el sistema de control automático (microcontroladores, amplificadores de potencia, sensores, actuadores, motores, motores, etc.) | Sistema de control desarrollado | Sistema de control automático en funcionamiento (100 %)
Implementación de un sistema mecánico portante del panel solar y su orientación mediante el uso de motores eléctricos en los dos ejes de movimientos acimutal y de elevación. | Diseño del sistema mecánico que permite el movimiento del panel solar, su rotación a través de los motores en dos ejes | Sistema mecánico desarrollado | Sistema mecánico en funcionamiento (100 %)
Integración de sistemas mecánicos, eléctricos y electrónicos. Ajustes. | Consolidación de los sistemas electrónicos, mecánicos y eléctricos y puesta a punto en laboratorio | Sistema completo del seguidor solar integrado | Sistema completo del seguidor solar en funcionamiento (100 %)
Implementación del control de seguimiento mediante la programación en tiempo real de los microcontroladores. | Programación de los microcontroladores | Control de seguimiento desarrollado | Control de seguimiento en funcionamiento (100 %)

Ajustes y prueba en campo. | Revisión general del funcionamiento de todos los sistemas involucrados | Seguidor solar en estado operativo. Pruebas de campo | Seguidor solar en funcionamiento (100 %
Elaboración de documentación (Legajo Técnico - Informe Final) | Registro documental de todas las actividades desarrolladas | Legajo técnico del Seguidor solar | Legajo técnico del Sun Tracker (100 %)

### 5. CUADRO DE AVANCE CRONOLÓGICO DEL PROYECTO

Objetivos | Actividades | Fecha programada | Fecha efectiva
Inicio | Fin | Inicio | Fin
Investigación de sensores, motores, componentes electrónicos y servicios especializados de provisión de partes mecánicas existentes en el mercado local y de un seguidor solar. | Estudio, relevamiento, análisis y comparación de la información obtenida | Febrero 2019 Abril 2019 | Diciembre 2019 Febrero 2020
Implementación de sistema de sensado de luz solar. Adquisición de componentes | Elaboración de listado tentativo de componentes a adquirir | Mayo 2019 Julio 2019 | Marzo 2020 Mayo 2020

Desarrollo e implementación de sistema de control mediante microcontroladores y amplificadores de potencia para la lectura de los sensores y actuación de los motores destinados para los ejes de movimientos acimutal y de elevación. | Diseño e implementación de todo el sistema de control automático (microcontroladores, amplificadores de potencia, sensores, actuadores, motores, motores, etc.) | Julio 2019 Agosto 2019 | Mayo 2020 Junio 2020
Desarrollo e implementación de un sistema mecánico portante del panel solar y su orientación mediante el uso de motores eléctricos en los dos ejes de movimientos acimutal y de elevación | Diseño del sistema mecánico que permite el movimiento del panel solar, su rotación a través de los motores en dos ejes | Agosto 2019 Septiembre 2019 | Julio 2020 Agosto 2020
Integración de sistemas mecánicos, eléctricos y electrónicos. Ajustes. | Consolidación de los sistemas electrónicos, mecánicos y eléctricos y puesta a punto en laboratorio | Septiembre 2019 Octubre 2019 | Agosto 2020 Septiembre 2020
Implementación del control de seguimiento mediante la programación en tiempo real de los microcontroladores. | Programación de los microcontroladores | Octubre 2019 Noviembre 2019 | Octubre 2020 Noviembre 2020
Ajustes y prueba en campo. | Revisión general del funcionamiento de todos los sistemas involucrados | Noviembre 2019 Noviembre 2019 | Diciembre 2020 Febrero 2021
Elaboración de documentación (Legajo Técnico - Informe Final) | Registro documental de todas las actividades desarrolladas | Noviembre 2019 Diciembre 2019 | Febrero 2021 Marzo 2021

### 6. CUADRO DE EJECUCIÓN DEL FINANCIAMIENTO

Objetivos | Rubro de Financiamiento | Insumos (Cantidad y Tipo) | Costo Unitario Insumo | Costo Total Insumo

Equipamiento

Bienes de consumo

Pasajes

Gastos de movilidad

Viáticos y alojamiento

Total invertido en el UNDEFI N° 263/18

Monto de la devolución de fondos no utilizados

Total | $ 115.000

### 7. SUGERENCIAS y/o APRENDIZAJES QUE CONSIDERE OPORTUNOS

a) El monto para compras directas ($ 3.000) al inicio del UNDEFI ha quedado muy desactualizado a causa de la inflación y de la devaluación producida. Igual criterio se aplica al tope de $ 50.000 como valor máximo en una compulsa de precios entre no menos de tres proveedores.
b) La duración máxima posible de un UNDEFI fijada en un (1) año resulta exigua para poder alcanzar con éxito los objetivos que se establezcan. Se sugiere una duración mínima de dos
(2) años.
c) Resulta razonable considerar para los UNDEFI que la UNDEF proponga en el futuro, que además de otorgar financiamiento para el desarrollo de los mismos (insumos, equipamiento, bibliografía, servicios y/o asistencia técnica especializada, viajes y viáticos, inscripción a congresos y eventos) se prevea las horas a asignar a los docentes-investigadores que en ellos se desempeñen o se les otorgue algún tipo de dedicación académica (simple, semiexclusiva o exclusiva), acordes con el régimen vigente en una Universidad Nacional..
d) Cabe destacar finalmente, que las limitaciones impuestas por la pandemia, en especial durante el año 2020, en cuanto al ASPO primero y el DISPO después, afectaron el normal desarrollo del UNDEFI, obligaron a realizar todas las tareas de montaje en el domicilio particular de los investigadores, sumado a la falta stock de determinados materiales y componentes propios de los proveedores, a pesar de todo esto, se alcanzó el objetivo propuesto.

Firma del Director del Proyecto | Firma de Unidad Académica Ejecutora

Anexo 1

UNDEFI N° 263/18
Legajo Técnico (Sun Tracker)

### 1. Aplicaciones del Sun Tracker

El Sun Tracker (ST) o Seguidor Solar o Rastreador Solar, es un dispositivo utilizado para orientar un panel fotovoltaico, reflector, lentes u otros dispositivos ópticos hacia el sol. Dado que la posición del sol en el cielo cambia con las estaciones y la hora del día, los rastreadores se utilizan para alinear el sistema de recolección para maximizar la producción de energía.

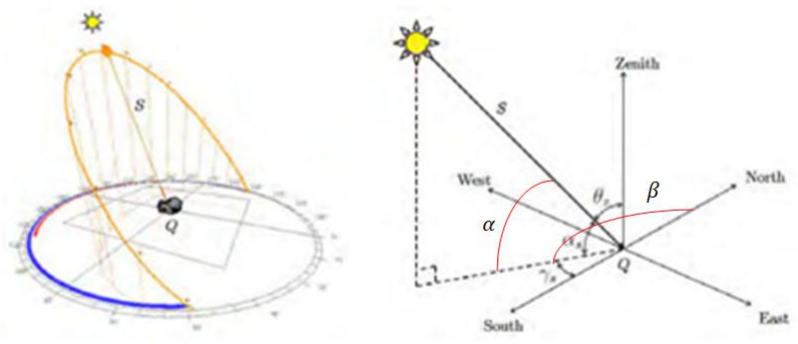
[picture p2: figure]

Figura N°1.1.Trayectoria del sol, que depende de la zona geográfica. El ángulo α es el de elevación tomado respecto al plano horizontal, y el ángulo β es el de acimut tomado respecto al Norte.

Figura N°1.2.Trayectorias del sol, en una zona geográfica determinada, tomadas durante todo el año.

Se deben considerar varios factores al determinar el uso de rastreadores. Algunos de estos incluyen:

- La tecnología solar que se utiliza.
- La cantidad de irradiación solar directa.
- Las tarifas de alimentación en la región donde se implementa el sistema.
- El costo de instalación.
- Mantenimiento de los rastreadores.
ST utilizado con paneles fotovoltáicos | STutilizado con paneles parabólicos térmicos Figuras N°1.3

El uso de un ST puede mejorar la potencia total producida por el sistema y pueden ser muy efectivos.
2. Tipos de Sun Tracker.
Hay muchos tipos de ST, de diferentes costos, sofisticación y rendimiento. Las dos categorías básicas de seguidores son eje único y eje doble.
2.1. Sun Tracker de eje único.
Los ST pueden tener un eje horizontal o vertical. El tipo horizontal se usa en regiones tropicales donde el sol se pone muy alto al mediodía, pero los días son cortos. El tipo vertical se utiliza en latitudes altas donde el sol no se pone muy alto, pero los días de verano pueden ser muy largos. En aplicaciones de energía solar concentrada, los ST de un solo eje se utilizan con diseños de espejo Fresnel parabólicos y lineales.
2.2. Sun Tracker de doble eje.
Los ST tienen un eje horizontal y uno vertical y, por lo tanto, pueden seguir el movimiento aparente del sol prácticamente en cualquier parte del mundo. El seguimiento de doble eje es extremadamente importante en aplicaciones de torres solares debido a los errores de ángulo resultantes de distancias más largas entre el espejo y el receptor central ubicado en la estructura de la torre. Muchas aplicaciones fotovoltaicas solares tradicionales emplean ST de dos ejes para colocar los paneles solares perpendiculares a los rayos del sol. Esto maximiza la potencia de salida total al mantener los paneles a la luz solar directa durante la cantidad máxima de horas por día.

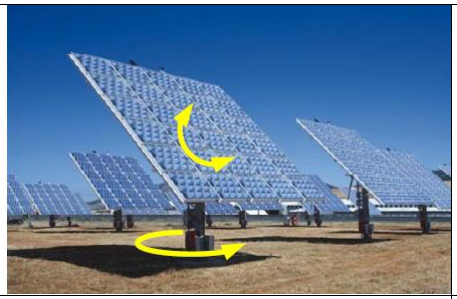
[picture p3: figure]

ST de doble eje para aplicaciones de paneles solares fotovoltaicos (PV)

ST de doble eje para placas solares térmicas / aplicaciones de motores
Figuras N°1.4

### 2.3. Componentes del Sun Tracker

Los elementos principales de un sistema de seguimiento son los siguientes:
a) Algoritmo de seguimiento del sol: este algoritmo calcula el azimuth solar y los ángulos de elevaciónes del sol.
b) Estos ángulos se utilizan para colocar el panel solar o el reflector para apuntar hacia el sol. Algunos algoritmos son puramente matemáticos basados en referencias astronómicas, mientras que otros utilizan lecturas de intensidad de luz en tiempo real.
c) Unidad de control: la unidad de control ejecuta el algoritmo de seguimiento solar y coordina el movimiento del sistema de posicionamiento.
d) Sistema de posicionamiento: el sistema de posicionamiento mueve el panel o reflector para mirar al sol en los ángulos óptimos. Algunos sistemas de posicionamiento son eléctricos y otros hidráulicos. Los sistemas eléctricos utilizan codificadores y variadores de frecuencia o actuadores lineales para monitorear la posición actual del panel y moverse a las posiciones deseadas.
e) Mecanismo de transmisión: incluyen actuadores lineales, unidades lineales, cilindros hidráulicos, unidades giratorias, engranajes helicoidales, engranajes planetarios y husillos roscados.
f) Dispositivos de detección: para los ST que utilizan la intensidad de la luz en el algoritmo de seguimiento, se necesitan piranómetros para leer la intensidad de la luz. También puede ser necesario monitorear la condición ambiental de presión, temperatura y humedad para optimizar la eficiencia y la potencia de salida.
g) Los interruptores de límite se usan para controlar la velocidad y evitar exceso de recorrido para evitar daños en el rastreador.

h) La retroalimentación de elevación se logra mediante 1) una combinación de interruptores de límite y conteos del codificador del motor, o 2) un inclinómetro (un sensor que proporciona el ángulo de inclinación).
i) Se usa un anemómetro para medir la velocidad del viento. Si las condiciones del viento son demasiado fuertes, los paneles generalmente se conducen a una posición horizontal segura y permanecen en la posición de seguridad hasta que la velocidad del viento cae por debajo del punto de ajuste.

### 3. Tareas realizadas

1) Investigación de paneles solares, sensores, motores, componentes electrónicos y servicios especializados de provisión de partes mecánicas existentes en el mercado local.
2) Presupuestado de los componentes.
3) Implementación del sistema de sensado de luz solar.
4) Pruebas del panel solar bajo radiación solar y cargado con motores para evaluar su eficiencia.
5) Investigación y desarrollo de partes mecánicas de la estructura portante del panel solar y sistema de orientación con movimientos de elevación y acimut. Por ser un prototipo, las partes mecánicas se realizarán mediante impresión 3D y no se tendrán en cuenta el efecto de la UV.
6) Investigación, desarrollo e implementación del sistema de control mediante microcontroladores y amplificadores de potencia para la lectura de los sensores y actuación de los motores destinados para los ejes de movimientos de elevación y azimutal.
7) Desarrollo e implementación de un sistema mecánico portante del panel solar y su orientación mediante el uso de motores eléctricos en los dos ejes de movimientos de de elevación y azimutal.
8) Integración de los sistemas mecánicos, eléctricos y electrónicos y realización de los ajustes correspondientes.
9) Implementación del control de seguimiento mediante la programación en tiempo real de los microcontroladores.
10) Realización de los ajustes y las pruebas en campo.
11) Documentar toda la información (en papel y digitalizada) surgida del Proyecto.

### 4. Módulo fotovoltaíco policristalino de alto rendimiento

### 4.1. Características generales

Los módulos solares Solartec son fabricados en base a celdas fotovoltaicas de silicio policristalino de alta eficiencia de conversión, que es superior al 14%.

Para protegerlas de los agentes atmosféricos y aislarlas eléctricamente, las celdas son encapsuladas con material plástico EVA (etil-vini-acetato) estable a la radiación ultravioleta. El frente expuesto al sol es de vidrio templado de alta transparencia (bajo contenido de hierro) y de 3mm de espesor, lo que le otorga una mayor resistencia al impacto. La cara posterior es de TPE, una lámina compuesta de elevada resistencia mecánica y eléctrica.
El marco de aluminio anodizado asegura la rigidez estructural y facilita su instalación. La bornera fijada a la cara posterior permite su interconexión con los otros componentes del sistema. Suelen usarse en climas cálidos pues pueden absorber el calor a una mayor velocidad y son afectados en menor medida el calentamiento. Son más económicos que otros.

MODELO SOLARTEC KS45TA
CARACTERÍSTICAS ELÉCTRICAS | CARACTERÍSTICAS MECÁNICAS
POTENCIA NOMINAL (PN) | 45Wp | LARGO (c) | 868mm
TENSIÓN A PN | 15,9V | ANCHO (b) | 343mm
CORRIENTE A PN | 2,84A | ESPESOR | 36mm
TENSIÓN A CIRCUITO ABIERTO | 18,8V | PESO | 3,7Kg
CORRIENTE A CORTO CIRCUITO | 3,01A | ***

Figura N°3.1. Modelo KS45TA

Figura N°3.2. Curva CorrienteVs Tensión y dimensiones físicas

### 4.2. Determinación de las inercias

Según el siguiente esquema, el movimiento de elevación se hará girando alrededor del eje z y el movimiento de acimut, alrededor del eje y. sobre el eje x no hay movimiento.

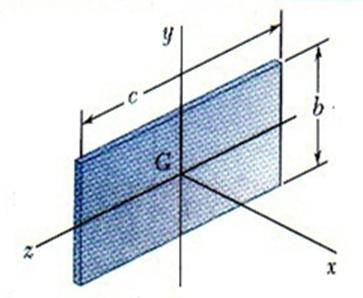
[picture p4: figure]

Figura N°3.3. Dimensiones en Características mecánicas

Las ecuaciones para la determinación de las inercias de acuerdo a los ejes x, y y z son:

4.Modelo matemático de los motores de continua

Los motores empleados para los movimientos azimutal y de elevación idénticos y poseen reductor de engranajes. Se explicará y modelizará uno de ellos.

### 4.1. Principio básico de funcionamiento

Figura Nº4.1: Esquema conceptual de un motor de corriente continua

El motor de cc es básicamente un transductor de torque que convierte energía eléctrica en energía mecánica. El torque desarrollado en el eje del motor es directamente proporcional al flujo magnético y la corriente de armadura.
Como se ve en la figura Nº4.1, un conductor circula una corriente estando éste dentro un campo magnético, aparecerá una fuerza que tiende a desplazar al conductor y a su vez, se generará una tensión en sus extremos que es proporcional a la velocidad del eje del motor y tiende a oponerse a la corriente del flujo. Veamos ahora la Fig. Nº4.2, en donde el eje del motor es el Centro de rotación, el conductor se encuentra arriba a una distancia r (radio deo rotor), la corriente I circula ingresando en la imagen, y sobre el conductor incide el Flujo magnético orientado radialmente uniforme , y es constante, generado por un imán permanente. Esto hará que aparezca una fuerza F que forzará al conductor desplazarse en sentido antihorario describiendo una trayectoria circular de radio r.

Figura Nº 4.2. Esquema conceptual de la física del motor

Donde:
φ :

flujo magnético orientado uniformemente y radialmente (constante).
: Kt | [ | ]
A

Nm
constante de proporcionalidad entre corriente de armadura y torque

T K i (t) =
t a
(1) al circular corriente, se induce una fcem o back emf.
eb = Ktφω m Þ Kb = Ktφ
:Cte. Fecm (Fuerza Contra Electromotriz Inducida).

: ω m
velocidad angular de rotación del conductor.

### 4.2. Modelo matemático

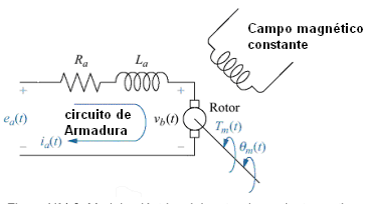
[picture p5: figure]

Figura Nº4.3: Modelo eléctrico del motor de corriente continua

Donde:
i (t) :
a

corriente de armadura

[A].

: Ra
resistencia de armadura

[Ω].

: La
inductancia de armadura

[Hy].

e (t) v (t) :
b = b
Fuerza Contra Electromotriz Inducida o back emf

[V].

T (t) :
l

torque antagónico o de carga

[N.m].

T (t) : m
torque entregado por el motor

[N.m].

(t) : θ m
desplazamiento angular del rotor

[rad].

(t) : ω m
velocidad angular del rotor

[rad seg].

e (t) :
a

tensión aplicada en la armadura

[V].

: m

J
inercia del rotor

[ ] 2 Kg.m .

: Bm
coeficiente de fricción viscosa

[N.m.s rad].

( )

( )
( ) | ( ) | e t
dt

di t
e t | R i t | L | b

a
a

=

a a | + a | +

(2)

( )

( )
( ) | K | t
dt
d | t
e t | K | b | m

m
b | b | ω

θ
= | =

(3)

( )

( ) | ( )
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
d | t
T t | J | l

m
m

m
m

=

m | + | +
θ | θ
(4)

Despejando | de (2):

a

b
a
a

a

a

a | a
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
di t | ( )
( )
( ) | ( )
= | - | -

y reemplazando

e (t) b
de (3):

m
a

b
a
a

a

a

a | a
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
di t
= | - | ( ) - | ω
( ) | ( )

nos queda:

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
- = | - | - | ω
despejando | de (4):

m

m | l

m

m

m

m | m
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
d | (t) | ( ) | ( ) | ( )

2

2
= | - | -
θ | θ

como:

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
entonces:
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
m | t
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
d | t | ( )
( )

( )
= | - | ω | -

ω

nos queda:

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
ω = | - | ω -

además:
θ m
= ω m

finalmente el espacio de estado en forma matricial es: Ecuaciones de estado:

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
0 | 1 | 0

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
[ ] a
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
[ ] Tl

y las ecuaciones de salida: (referida a la posición angular

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
y | ω θ
1 0 0

Con este espacio de estado y los datos de los motores, se pueden armar las matrices para ser cargados en Matlab y éste haga los cálculos y simulaciones necesarias.

### 4.3. Diagrama de Mason

Figura Nº4.4: Diagrama de Mason del motor de corriente continua

Con el diagrama anterior (Fig. Nº4.4), se puede armar el diagrama en bloques para ser utilizado en Simulink. Se aclara que donde dice

K m
debe decir

Kt

### 4.4. Motor adoptado

Por su sencillez, costo y disponibilidad, se eligió el motor con reductor (motorreductor) de la firma Ignis, modelo MR08D-012004-4.0, el mismo posee un motor de corriente continua Mabuchi.

Los parámetros del motorreductor algunos pueden calcularse directamente de la información aportada por los fabricantes (Mabuchi e Ignis) y otras deben ser medidas experimentalmente.

### 4.4.1. Especificaciones

- Modelo motor: Mabuchi RS-385PH-2085.
- Modelo motor con reductor: MR08D-012004-4.0.
- Origen: Argentina/China.

De la hoja de datos del motor Mabuchi, se tiene la siguiente información:
a) Rango de operación:

Ea

= 9V → 30V .
b) Tensión de armadura nominal:

EaNom

= 6V .
c) Operación en vacío (No Load):
- Velocidad angular de giro:
rad seg mNL ω | = 795,87 | .
- Corriente de armadura:

I
aNL

= 0.15A.
- Torque entregado por el motor:

TmNL

= 0Nm .
d) Operación a máxima eficiencia (At Maximum Efficiency):
- Velocidad angular de giro:
rad seg mME ω | = 642,98 | .
- Corriente de armadura:

I
aME

= 0,63A.
- Torque entregado por el motor:

TmME

= 0,007541Nm .
e) Operación a rotor bloqueado (Stall):
- Velocidad angular de giro:
rad seg mS ω = 0 | .
- Corriente de armadura:

I
aS

= 2,65A.
- Torque entregado por el motor:

TmS

= 0,0392266m .

### 4.4.1.1. Constante de proporcionalidad

Observando el siguiente gráfico de la hoja de datos del motor Mabuchi:

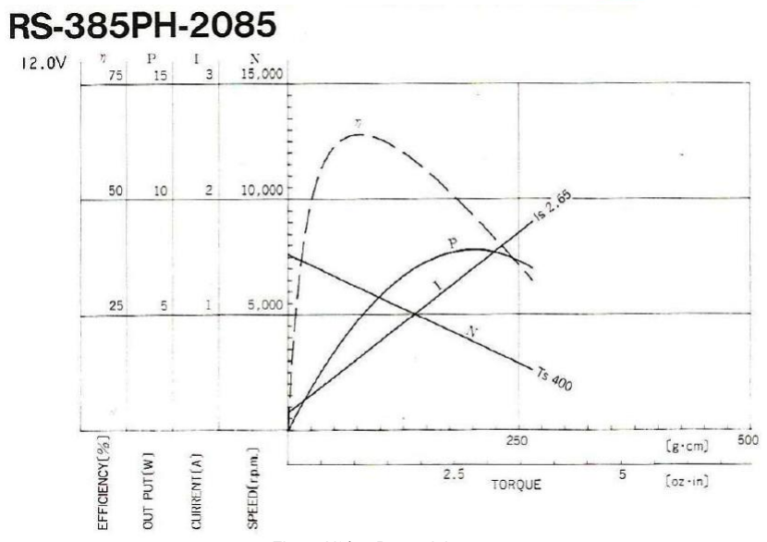
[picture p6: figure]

Figura Nº4.5: Datos del motor

En la Fig. Nº4.5 se observa la relación lineal entre la corriente de armadura
a

I
y el torque del motor
Tm
, y con los datos anteriormente enumerados, podemos calcular la constante de proporcionalidad Kt
. Observando el gráfico se tiene que:
a | aNL | Kt | Tm
I | I | .

-1
= +

despejando

aNL I
:
aNL | a | Kt | Tm
I | I | .

-1
= -

para operación a máxima eficiencia:

aNL | aME | Kt | TmME I | I | .

-1
= -

y a rotor bloqueado:

aNL | aS | Kt | TmS I | I | .

-1
= -

igualando ambas ecuaciones:

aME | t | mME | aS | Kt | TmS I | K .T | I | .
-1 | -1
- | = | -

despejamos :

aS | aME
mS | mME
t
I | I
T | T
K
=

reemplazando valores:

A | A
Nm | Nm Kt
2,65 | 0,63
0,0392266 | 0,001541
=

finalmente:

| A
K | Nm
t

= 0,01866

### 4.4.1.2. Constante de proporcionalidad

Relación entre y

Potencia eléctrica desarrollada en la armadura: P e (t)i (t) = b a

Potencia mecánica:
P T (t) | (t) =
m | ω m
(7)

además:

m

m
a
K

T t
i t

( )
( ) =

(8)

b | m | Kb

e (t) =ω (t)
(9)
despejando | en (8) y reemplazándola con (9) en (7):
m | m
m

m
b a | m | b | T
K

T
P = e i =ω K =ω .

en el sistema de medidas MKS, numéricamente:
[ ]
úû

ù
êë

é =
rad

Vseg K
A

K Nm
m | b

seg

rad K | V
b = 0,01866

### 4.4.1.3. Resistencia de armadura

Surge del cociente entre la tensión de armadura y corriente de bloqueo.

A

V
I

Ea R

aS

a
2,65

|12
= =

Ra
= 4,53Ω

### 4.4.1.4. Inercia del rotor

Este dato no es aportado por el fabricante, por lo tanto al rotor se lo considera como un cilindro cuya inercia deberá calcularse a partir de datos que son medidos.
De la Fig. Nº4.6, calculamos el momento de inercia de un cilindro de masa M, radio R y longitud L respecto de su eje Z.

Figura Nº4.6. Cilindro representativo del rotor

Tomamos un elemento de masa que dista x del eje de rotación. El elemento es una capa cilíndrica cuyo radio interior es x, exterior x+dx, y de longitud L, tal como se muestra en la figura. La masa dm que contiene esta capa es:

x dx
R

M
x dx L
R L

M
dm | . .
| 2.
| .2. . . .
2 | 2
= | π | =
π

El momento de inercia del cilindro es:

2

0

3
2
2

1

2.
x dx M R
R

M
J

R

m

= | = ò

Desarmando un motor, se rescató al rotor del cual se lo pesó mediante una balanza digital de laboratorio y se midió su diámetro con un calibre, dando los siguientes resultados de las mediciones:
- Peso rotor: | .
- Diámetro: | .
- Reemplazando valores en
m

J
:

# Página 25 de 75 ²

2

0,024
.0,03 .
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
Jm | Kg

Finalmente:

2
Jm | = 0,00000216Kgm

### 4.4.1.5. Inductancia del rotor

Dato no aportado por los fabricantes, con lo que se lo midió mediante un medidor de inductores de laboratorio, arrojando la siguiente indicación:
L | mHy a
= 19.2

### 4.4.1.6. Fricción viscosa

Dato no aportado por los fabricantes, es difícil de medir, sobre todo en un motor pequeño, es un dato estimado, que con el conocimiento de la velocidad angular del motor en vacío y mediante la simulación efectuada en Matlab (después se verá en el script mr08d.m), se ajustó de manera que en régimen permanente, la respuesta al escalón de una velocidad angular que se aproxime a la aportada por el fabricante del motor. Es un dato sobre el cual hay incertidumbre.

rad

Nmseg B | x m
5

0.4 10-
=

### 4.4.1.7. Reductor de engranajes

- Juego (Backslash): menor a 2º.
- Etapas desmultiplicación: 5.
- Desmultiplicación: 1.536:1, | .

Como el motor posee reductor de engranajes, y los mismos están construidos en resina acetálica siendo estos de muy bajo peso, su inercia es despreciable frente al del rotor. (Figura Nº4.7).

Figura Nº4.7. Reducción de engranajes de tipo planetario

### 4.4.1.8. Dimensiones físicas

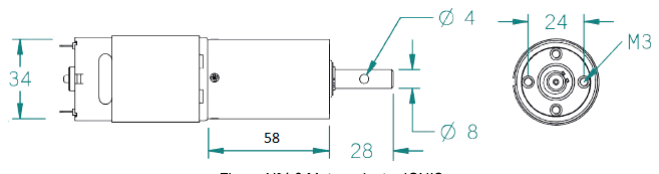
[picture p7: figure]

Figura Nº4.8:Motorreductor IGNIS

### 4.5. Determinación de la inercia total para ambos movimientos

Dada la alta reducción de engranajes, las inercias según los ejes z e y del panel solar, quedarán despreciables frente a las del motor respectivo de esos movimientos.

### 4.5.1. Inercia equivalente para motor movimiento de elevación

### 4.5.2. Inercia equivalente para motor movimiento azimutal

### 4.6. Simulaciones a lazo abierto

Una vez determinado todos los parámetros de los motores para ambos movimientos, se determinará la función de transferencia de los motores en forma exacta y simplificada, se las comparará entre ellas para verificar su similitud y se graficará la respuesta al escalón de tensión de armadura de la posición angular, velocidad angular sobre el eje a la salida del reductor y el torque entregado en el eje del motor. La simulación se efectuará en Matlab.

### 4.6.1. Script en Matlab: mr08d4.m

% Motorreductor IGNIS MR08D

-012004

-4.0.
clear all;
clc; %-------------------------------------------------------------

% Datos del motor
% Inercia total
Jm = 0.00000216; %[kgm^2]
% Resistencia de armadura
Ra = 4.53; %[Ohm]
% Inductancia de armadura
La = 19.2E | -3; %[Hy]
% Tensión nominal aplicada al motor Ea = 12; %[V]
% Cte. proporc. Fecm
Kb = 0.018686; %[V/rad/seg]
% Cte. proporc. torquimétrica Kt = Kb; %[Nm/A]
% Fricción viscosa (estimado)
Bm = 0.4E | -5; %[Nmseg/rad]
% Reducción de engranajes
N = 1/1536; %-------------------------------------------------------------

%Matrices del sistema'
A = [ 0 1 0
0

-Bm/Jm Kt/Jm
0
-Kb/La | -Ra/La];
% Matriz de entrada
B = [0 ; 0 ; 1/La];
% Matriz de salida
% C = [Theta Omega ia]
C = [1 0 0];
% Matriz de realimentación
D = [0];
G_Theta = (ss(A,B,C,D))*N; %------------------------------------------------------------- % Respuesta al escalón de posición angular

subplot(3,1,1)
step(Ea*G_Theta)
grid
xlim([0 1]);
xlabel('Tiempo'

)
ylabel('Posición angular (rad)'

)
title('Respuesta al escalón del MR08D

-4 a lazo abierto'

)

%-------------------------------------------------------------%Respuesta al escalón de velocidad angular % C = [Theta Omega ia]
C = [0 1 0];
G_Omega = (ss(A,B,C,D))*N; subplot(3,1,2)
step(Ea*G_Omega)
grid
xlim([0 1]);
xlabel('Tiempo')
ylabel('Velocidad angular(rad/seg)')
title('Respuesta al escalón del MR08D-4 a lazo abierto') %-------------------------------------------------------------
'Función de transferencia G(s)=Theta(s)/Ea(s) a lazo abierto:' [Num,Den] = ss2tf(A,B,C,D);
G_s = (tf(Num,Den))*N
zpk(G_s)

%-------------------------------------------------------------%Respuesta al escalón del torque
% C = [Theta Omega ia]
C = [0 0 Kt/N];
G_Tm = ss(A,B,C,D);
subplot(3,1,3)
step(Ea*G_Tm)
grid
xlim([0 1]);
xlabel('Tiempo')
ylabel('Torque(Nm)')
title('Respuesta al escalón del MR08D-4 a lazo abierto')

Cuya salida al Command Window es:

Función de transferencia G(s)=Theta(s)/Ea(s) a lazo abierto:

( )

( )
( )
= | =
E s

s
G s

a

θ m

293.3 s
----------------------------------s^3 + 237.8 s^2 + 8856 s

Forma cero, polo ganancia:

( )

( )
( )
= | =
E s

s
G s

a

θ m

293.34 s
------------------------------s (s+191.6) (s+46.23)

Figura Nº4.9 respuesta al escalón de las salidas más importantes del motor

### 4.6.2. Diagrama en bloques en Simulink MR08D_la.mdl

La figura Nº4.10 es el diagrama que representa el modelo en bloques del espacio de estado del motor Ignis MR08D-4.

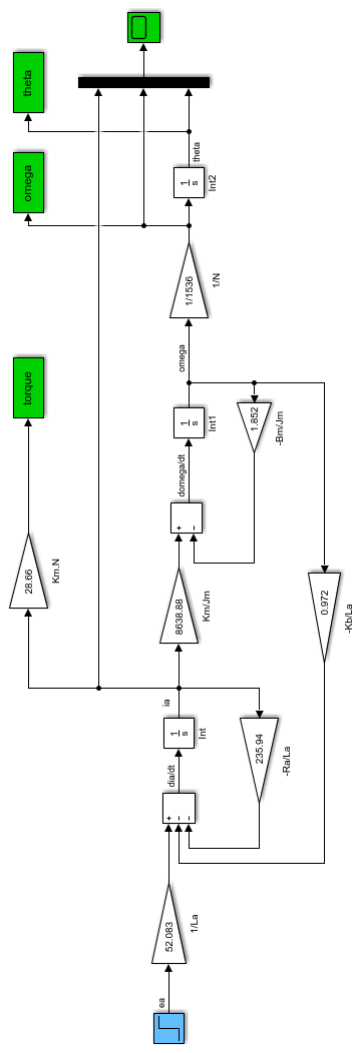
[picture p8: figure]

Figura Nº4.10: Diagrama en bloques del MR08D-04

### 4.6.3. Script en Matlab: Resp_mr08d.m

Este script grafica los resultados que salen de la simulación del diagrama en bloques MR08D4_la.mdl
% Grafica las señales de cada estado
% del motor Ignis MR08D-4.
clc;

% Grafica posición angular subplot(3,1,1);
plot(tout,theta)
grid
xlabel('Tiempo[seg]')
ylabel('theta(t) [rad]')

title('Respuesta al escalón del IGNIS MR08D-4')

% Grafica velocidad angular
subplot(3,1,2);
plot(tout,omega)
grid
xlabel('Tiempo[seg]')
ylabel('omega(t) [rad/seg]')

% Grafica Torque del motor subplot(3,1,3);
plot(tout,torque)
grid
xlabel('Tiempo[seg]')
ylabel('Torque(t) [Nm]')

Cuya salida al Command Window es:

Figura Nº4.11: Simulaciones obtenidas del diagrama en bloques del MR08D-4

### 5. Control de accionamiento para los dos motores

### 5.1. Concepto de Modulación de Ancho de Pulso (PWM)

Una forma alternativa al control de velocidad por variación de la tensión entre bornes, es la modulación de ancho de pulso (pulse width modulation o PWM). En este esquema, el sistema de control produce un tren de pulsos cuadrados, con la menor pendiente de crecimiento y decrecimiento posible, donde se mantiene constante el período del tren de pulsos
per t

y se varía el
ciclo de actividad o ancho de los pulsos
pw t

. La tensión máxima es fija. Se denomina ciclo de Actividad, o Duty D a :

per

pw
t

t
D =

y la velocidad angular sobre el eje del motor será:

K

E
D

amáx
m ω = .

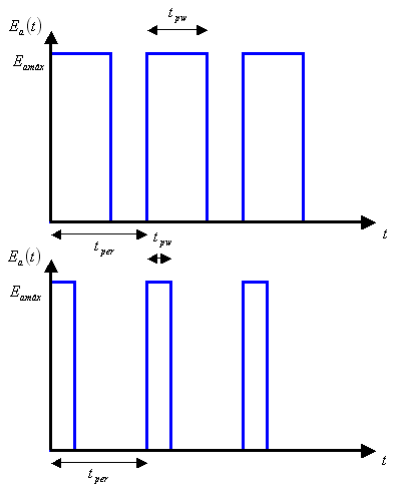
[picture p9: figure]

Figura Nº5.1: Control de velocidad de motores de corriente continua mediante PWM

En la Fig. Nº5.1, en el primer tren de pulsos, la tensión media sobre el motor es mayor al correspondiente al segundo tren de pulsos.
El control de velocidad se efectúa variando el duty, de manera que sobre el motor se desarrolla una tensión media proporcional al duty.
En la práctica, se trata de que el período no sea menor a 100Hz, porque sino el motor avanza “dando pasos”, pero tampoco mayor a 1KHz, porque entra en juego la reactancia inductiva de bobinado de la armadura y limita la corriente con la reducción del torque.
Este tipo de ondas cuadradas son muy fáciles de generar cuando el control se basa en un microprocesador. En sistemas así, el PWM se genera de forma discreta, por lo general utilizando el reloj del procesador como base de tiempo. De esta forma, todos los intervalos de tiempo involucrados (
pw t

y
per t

) serán múltiplos de alguna unidad mínima. Entra entonces en juego el concepto de resolución. Si bien el PWM se puede efectuar mediante un microcontrolador, el manejo de los motores de corriente continua requiere un amplificador de potencia que es un puente H.

### 5.2. Modelo básico puente H

Implementa modulación por ciclo de actividad o ancho de pulso.
Sobre el motor hay cuatro switches de control, pueden ser transistores bipolares o TMOS trabajando en conmutación, o sea, al corte y saturación.
El motor completa el puente H.

Figura N°5.2: Esquema simplificado conceptual del puente H

### 5.3. Operación del puente H

### 5.3.1. Sentido de giro del motor para un lado

Figura N°5.3: Corriente circula hacia derecha, supone que el motor gira en sentido horario

### 5.3.2. Sentido de giro para el otro

Figura N°5.4: Corriente circula hacia izquierda, supone que el motor gira en sentido antihorario

### 5.3.3. Frenado del motor

Se para libremente. Como el motor es un transductor reversible, esto es, se aplica una magnitud física eléctrica (tensión en bornes), convierte en otra magnitud física mecánica (giro del eje), pero a su vez, si se gira el eje, se obtiene una tensión en bornes y actúa como generador o dínamo. Por lo tanto, al energizar el motor, aplicándole tensión en sus bornes, después de un período de tiempo, fijado por una constante de tiempo, adquiere una velocidad de rotación constante, pero al quitarle esa tensión, el motor trabaja automáticamente como generador y a su vez se está autoenergizando, por lo que el tiempo que tarda en detenerse será mayor al que tardó en alcanzar el régimen permanente de revolciones de giro.

Figura N°5.5: Distintas formas de cortar alimentación al motor para que se detenga libremente

Se para más rápido. Ni bien se quita alimentación al motor, automáticamente se pone en corto los bornes, para evitar que el motor se autoalimente.

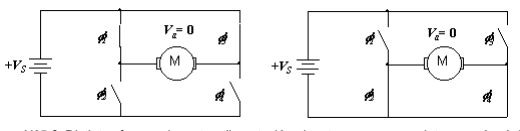
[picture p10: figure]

Figura N°5.6: Distintas formas de cortar alimentación al motor para que se detenga más rápido

### 5.3.4. Operación inválida del puente H

Estando cerrado los switches de una misma rama, pone en cortocircuito la alimentación. Ésta es una condición peligrosa, porque puede destruir los dispositivos de corte y saturación (transistores bipolares o TMOS). Debe ser tenida en cuenta en el algoritmo de control para que no suceda, y debe considerarse un circuito de protección.

Figura N°5.7: Distintas formas de poner en cortocircuitos los elementos de conmutación

### 5.3.5. Circuito completo del puente H del L298

Para el control de los motores del Sun Tracker, se adoptó el puente integrado L298. En este caso los switches o elementos de conmutación son transistores bipolares. Se muestra la lógica de control del puente aplicada a la entrada. Admite un máximo de corriente de carga de 2A.

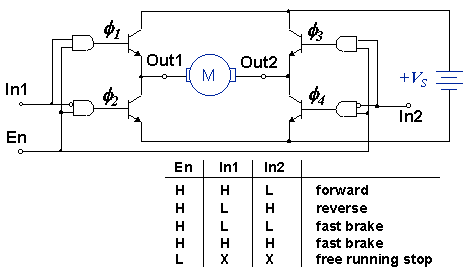
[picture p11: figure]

Figura N°5.8: Lógica de control del puente H L298

### 5.4. Circuito de protección por sensado de corriente

La salida del circuito integrado del puente H L298 da la posibilidad para la conexión a masa del puente H o puede ser conectado a masa a través de una resistencia de

0.1Ω.
Se coloca una resistencia de bajo valor dado que el sensado de una alta corriente o genera una caída de tensión variable que hace de divisor resistivo, además un valor alto de R, limita la corriente y por lo tanto el torque.

Vsense
es proporcional al torque.

Figura N°5.9:Sobre la resistencia Rs se mide la corriente que circula sobre el motor

### 5.5. Diodos rápidos de protección para “free wheels”

Durante la conmutación, y durante la desconexión del transistor, como el motor es una carga inductiva, mantiene almacenada energía que tiene que descargarla como corriente, por lo que aparecen picos de tensión que puede dañar al transistor.
Se ponen diodos rápidos en antiparalelo a cada transistor, para limitar la excursión de tensión y puentear al transistor.
Se requiere diodos de alta corriente y rápidos o “fast recovery” de
0.2µs .

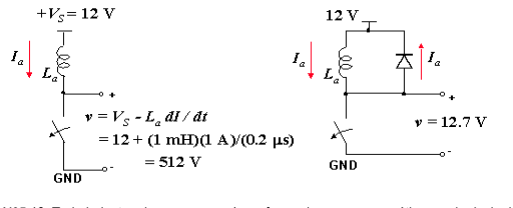
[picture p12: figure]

Figura N°5.10. Todo inductor almacena energía en forma de campo magnético que lo deviuelve con impulsos de tensión de muy alto valor y muy corta duración

### 5.6. Puente H con diodos flyback

Se colocan cuatro diodos en antiparalelo a cada transistor lo que derivan la energía almacenada en el motor durante la apertura de los switches, entre la alimentación y tierra. Esto evitará que cuando en la parte del PWM donde no se encuentra el pulso, el motor no estará alimentado y actuará como generador circulando una cotriente en contra de los transistores, y para evitar su destrucción, la corriente se derivará por los diodos, devolviéndola a la fuente.

Figura N°5.11: los diodos evitan que la corriente desarrollada por el motor circule por los transistores

### 5.7. Información del puente H adoptado

Se muestra una información mínima obtenida de la hojas de datos (data sheet) del circuito integrado utilizado, que corresponde al L298.

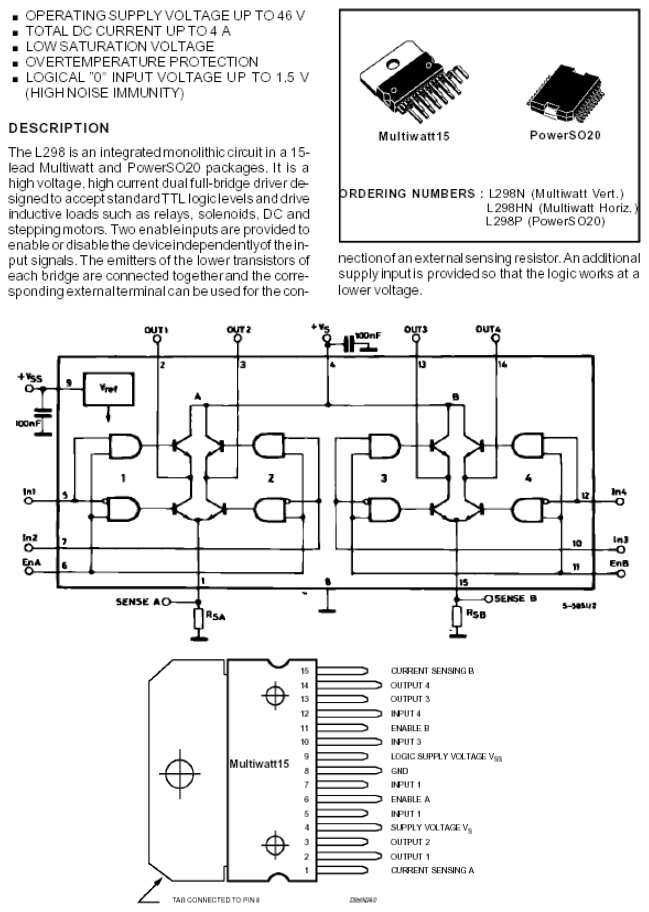
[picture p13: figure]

Figura N°5.12. Extracto del data sheet del L298

### 5.8. Determinación constante de proporcionalidad del puente H y PWM

En el circuito integrado adoptado hay dos puentes H gemelos e independientes entre si, cada uno para manejar el motor de cada eje del Sun Tracker. A la entrada de los mismos se conectan la salidas de los timer configurados como generador de PWM del microcontrolador que realizará el control de los mismos, siendo el adoptado el Atmega8, los mismos tienen una resolución de 10 bits, y la amplitud de los pulsos corresponden a niveles altos CMOS (5Vcc), pero como los puentes H están alimentados con 12Vcc, la amplitud de los pulsos a la salida de los puentes H serán de 12V, por lo tanto, la constante de proporcionalidad queda definida como:

1024

D.5V.2.4V
KPWM
=

siendo D la palabra digital a la entrada de los timers configurados como PWM y varía entre 0 y 1023. Numéricamente:
bits K | V
PWM

= 0.0117

### 6. Controlador PID

El control adoptado el el clásico PID (Proporcional Integrativo Derivativo) Discreto, dado que el posicionamiento de la celda debe ser lento y con torque suficiente. El control es un algoritmo en tiempo real que es realizado por un microcontrolador de 8 bits, de la firma MICROCHIP-ATMEL y el micro adoptado es el Atmega328. Se hará a continuación una introddución del control PID.

### 6.1. Introducción

Cuando trabajamos con aplicaciones donde el control de la salida de un sistema ante cambios de la señal de referencia de entrada, la implementación de un algoritmo de control es necesario. Ejemplos de tales aplicaciones son control de motores, control de temperaturas, presión, flujo, velocidad, fuerza y otras variables. El controlador PID puede ser usado para controlar una variable medible. A continuación se ven las curvas de respuestas a una entrada escalón (traza roja), para un controlador Proporcional solamente (traza amarilla), para un controlador Proporcional-Integrativo (traza azul), y controlador Proporcional-Integrativo-Derivativo (traza verde).

Figura Nº6.1: Respuesta de distinto tipos de controladores a una entrada escalón

En la figura Nº6.2:

Figura Nº6.2: Sistema a lazo cerrado con controlador PID

el controlador PID compara el valor medido y del proceso (sistema) con un valor de referencia de setpoint r, la diferencia o error e, es entonces procesado para calcular un nuevo proceso de entrada u, de manera de generar una nueva entrada al sistema para que este tenga la salida deseada. La alternativa al esquema de control a lazo cerrado como el caso del controlador PID, es el controlador a lazo abierto (sin realimentación), que en la mayoría de los casos es insatisfactorio, y generalmente es imposible debido a las propiedades del sistema. Realimentando la salida del sistema, la performance del mismo puede ser mejorada.
El controlador PID es capaz de manipular las entradas del proceso basadas en la historia y la velocidad de cambio de la señal, esto da un método de control más exacto y estable.
La idea básica es que el controlador lea el estado del sistema por un sensor, y que se reste a la misma un valor deseado de referencia o setpoint para generar el valor de error. El error será manejado por tres vías, manejar el presente, a través del término proporcional, recuperarlo desde el pasado, usando el término integral y anticipar el futuro, a través del término derivativo.

### 6.2. Control proporcional

El Control Proporcional (P) da una entrada al sistema de control que es proporcional al error. Usando solamente el control P da un error estacionario en todos los casos salvo que el sistema sea tipo Cero y el valor de la salida del sistema sea igual al valor de referencia.

Figura Nº6.3: Respuesta al escalón del controlador P

En la figura Nº6.3 se muestra el error en estado estacionario entre el valor del proceso o salida del sistema y la entrada de referencia, donde se ve la diferencia en alturas entre la traza roja y la azul. Usando un alto valor de P puede dar lugar a un sistema inestable.

### 6.3. Control proporcional Integrativo

El control solo integral (I) es una acumulación de los errores previos sumado a la entrada del sistema de control. La operación de sumar el error continuará hasta que el valor del proceso de control sea igual al valor deseado de entrada, y esto resulta en una salida que no tiene error estacionario cuando la referencia es estable, tal como puede verse en la figura N°6.4, en la respuesta representada por la traza azul. El uso más común del término I es normalmente junto al P, llamando a esto como controlador PI.
En la figura Nº6.4 se muestra que la respuesta del controlador PI no tiene error estacionario (traza verde) comparada a un controlador P (traza amarilla) y que la respuesta del controlador I es muy lenta.

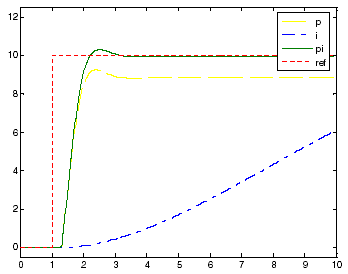
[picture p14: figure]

Figura Nº6.4: Respuesta al escalón de un controlador I y un controlador PI

### 6.4. Término derivativo

El control solo derivativo (D) da una adición de la velocidad de cambio en el error a la entrada del sistema de control (traza azul en figura N°6.5). Un cambio rápido en el error dará una adición a la entrada del sistema de control. El D es típicamente utilizado con P para dar lugara a un control Proporcional Derivativo (PD, ver traza verde en figura N°6.5) o con PI como controlador PID.
Un valor alto de D da a lugar un sistema inestable.

Figura Nº6.5: Respuesta al escalón de un controlador D y un controlador PD

La respuesta del controlador PD (traza en verde en Fig.N°6.5) da una respuesta más rápida a la correspondiente a un controlador P. Notar que el D se caracteriza esencialmente como un filtro pasaaltos sobre el error de la señal y fácilmente introduce inestabilidad y hace que sea más sensible al ruido. Usando todos los términos como un controlador PID usualmente da la mejor performance. En la figura Nº6.7:

Figura Nº6.7: Respuesta al escalón de un controlador P, de un PD y un PID

se comparan los controladores P, PI y PID. PI mejora el P removiendo el error estacionario, y el PID mejora al PI dando una respuesta más rápida sin tener sobrepico.

### 7. Control proporcional, integrativo y derivativo en forma discreta

El controlador digital es básicamente un procesador digital que cada T segundos resuelve un algoritmo recursivo (ecuación de diferencias) en tiempo real. El diseño del controlador digital suele ser realizado empleando técnicas propias de los sistemas muestreados.
Estas técnicas permiten obtener controles más versátiles que los que se pueden conseguir con compensadores analógicos.

Esquema Nº7.1 Sistema a lazo cerrado discreto con compensador PID en cascada

El diseño y ajuste es por prueba y error, se comienza con control P, luego se aplica un PI para eliminar o reducir el error permanente, y después un PID, con la parte derivativa para reducir el sobrepico y el tiempo de crecimiento.

### 7.1. Control proporcional

Se puede ajustar la ganancia del controlador, incrementando la ganancia del mismo, se reduce el error en régimen permanente, pero aumentará el sobrepico y se reducirá el amortiguamiento. El controlador Proporcional solamente no bastará.

### 7.2. Control proporcional integrativo

Es necesario un controlador más complicado para reducir el error en régimen permanente, para ello introducimos el controlador proporcional integrativo PI.
La forma del controlador PI que usaremos es:

ú
û

ù
ê
ë

é
= | Δ | + | ∑Δ

=

k
p | KiTs m k | K | k

0

( ) | ( ) | ( )

donde
Δ(k)

es la entrada del controlador y m(k)

es la salida, y

es una variable de la sumatoria que aproxima a la integral. La transformada z de la integral que entonces está aproximada por la sumatoria es:

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
la función de transferencia del controlador PI es:

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
( ) 1
z

z
GcPI z | K p | KiTs

para que queden evidentes los polos y ceros del controlador PI, rescribimos la función de transferencia como una función racional:

ú
û

ù
ê
ë

é

+ | -
=
1
(1 | ) | 1
( )
z

K T z
G | z | K

i s
cPI | p

de esta manera vemos que

G (z)
cPI

tiene un polo en
z =1

y un cero en
(1 | )

1
KiTs

z
+

=

que se encuentra a la izquierda del polo. Usando este controlador, nos aseguramos que la respuesta al escalón tenga error en régimen permanente nulo pero puede afectar adversamente al amortiguamiento.

### 7.3. Control proporcional integrativo derivativo

Con el controlador PI, esperamos que nuestro sistema de control satisfaga las especificaciones de sobrepico, tiempo de establecimiento y error en régimen permanente. Pero si se desea un menor tiempo de crecimiento sin incrementar el sobrepico, es necesario incluir un control derivativo. La aproximación en tiempo discreto del término derivativo agregado al controlador PI, el nuevo controlador PID está dado por:

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
æ Δ | - Δ -
= | Δ | + | ∑Δ | +
= | s

d

k

p | i s
T
k | k
m k | K | k | K T | K
( ) | ( | 1)
( ) | ( ) | ( )
- 0

donde
Δ(k)

es la entrada del controlador y m(k)

es la salida, la transferencia del PID es M(z) Δ(z)

que puede escribirse como:

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
G | z | K | K

s

d

s
cPID | p | i

1
1

( ) 1

para hacer visibles los polos y ceros del controlador PID, reescribimos la transferencia como una función racional de z:

ú
û

ù
ê
ë

é

+ | + | - + | +
=
( | 1)
(1 | ) | (1 2 | )
( )

2
z z
K T | K T z | K T z K T
G | z | K
i s | d | s | d | s | d | s
cPID | p

esta función tiene un polo en z =1

como tiene la función de transferencia del PI, pero además tiene un polo adicional en
z = 0

. También tiene dos ceros que pueden ser reales o complejos conjugados, dependiendo de los valores que el diseñador seleccione para

Kd
y

Ki
Se requerirán varias iteraciones para la determinación de las ganancias Kp

, Ki
y

Kd
hasta lograr
un funcionamiento óptimo.

### 7.4. Selección de Período de muestreo Ts

Es conveniente que Ts sea lo suficientemente pequeño para:

- Que la aproximación empleada en la discretización sea correcta.
- Que no se afecte la estabilidad del lazo.
- Que no se pierda información de la señal muestreada.

Efectivamente, por el teorema de muestreo de Shanon la frecuencia de muestreo debe ser por lo menos, el doble que la máxima frecuencia de la señal muestreada.
Sin embargo, el período de muestreo no puede ser reducido todo lo que se quiera, ya que existen, entre otras, limitaciones debidas a la velocidad de cálculo del procesador digital y dificultades debidas al 'redondeo' en las operaciones.
Otros factores a tener en cuenta en la selección del periodo de muestreo T son:
- Espectro de las perturbaciones.
- Tipo de actuador empleado.
- Equipo de medida.
- Costo computacional.

En nuestro caso, el algoritmo de control correrá bajo el microcontrolador Atmega8, donde el tiempo de muestreo mínimo obtenido es de 16mseg. Observando la función de transferencia del motor a lazo abierto, se puede ver que el ancho de banda es de
seg
Bw | rad = 5.436
, por lo tanto,

haciendo la relación entre frecuencia de muestreo y ancho de banda tenemos:

11,5
5.436

0.016

1
= | =
Bw

f
s
veces que
s

f
supera a Bw y es posible muestrear a Ts.

### 7.5. Simulaciones con controlador P, PI y PID discreto

Se efectuó el diseño y simulación de cada uno de los compensadores, para poder comparar sus ventajas y las ganancias fueron obtenidas por prueba y error en forma reiterada, mediante un proceso de optimización “artesanal” que consiste en la visualización del funcionamiento del sistema real, hasta que dio un funcionamiento satisfactorio, para todos los casos, siempre se evaluó que el funcionamiento fuera estable (polos del sistema a lazo cerrado dentro del círculo de radio unitario) y se partió con las condiciones que el sistema presentara un sobrepico dentro del 20% y que sea capaz de seguir a la rampa de
seg

rad 1
con error nulo, y ajustando las ganancias de manera que

de un mínimo de tiempo de establecimiento. Finalmente se implementará un PID discreto.

### 7.5.1. Script en Matlab: pidz_mr08d_total.m

% Diseño de compensadores P, PI y PID en forma discreta % para efectuar los controles de movimientos de toma
% y deja mediante los motores IGNIS MR08D-012004-4.0.

clc
clear all

%-------------------------------------------------------------% Datos del motor
% Inercia total
Jm = 0.00000216; %[kgm^2]
% Resistencia de armadura
Ra = 4.53; %[Ohm]
% Inductancia de armadura
La = 19.2E-3; %[Hy]
% Tensión nominal aplicada al motor Ea = 12; %[V]
% Cte. proporc. Fecm
Kb = 0.018686; %[V/rad/seg]
% Cte. proporc. torquimétrica Kt = Kb; %[Nm/A]
% Fricción viscosa (estimado) Bm = 0.4E-5; %[Nmseg/rad]
% Reducción de engranajes
N = 1/1536;

%-------------------------------------------------------------% Cte. del PWM: K_pwm = 5V*2.4/1024 %K_pwm = 0.1173;
K_pwm = 1;
%-------------------------------------------------------------%Matrices del sistema'
A = [ 0 1 0
0 -Bm/Jm Kt/Jm
0 -Kb/La -Ra/La];
% Matriz de entrada
B = [0 ; 0 ; 1/La];
% Matriz de salida
% C = [Theta Omega ia]
C = [1 0 0];
% Matriz de realimentación D = [0];

'Función de transferencia del motor Gm(s) en forma analógica:' [Num,Den] = ss2tf(A,B,C,D);
Gm_s = (tf(Num,Den))*N*K_pwm

%-------------------------------------------------------------
% Trazado LR
figure(1)
rlocus(Gm_s)
title('Lugar de Raíces del motor con el puente H')

'--------------------------------------------------------------------' % Datos para diseñar el PID.
'Período de muestreo:'
Ts = 0.016
'Constante integrativa:'
Ki = 0.5
'Constante proporcional:'
Kp = 50
'Constante derivativa'
Kd = 0.01
'--------------------------------------------------------------------' 'Función de transferencia del motor Gm(z)discreta:' % usamos la opción z.o.h.
Gm_z = c2d(Gm_s, Ts, 'zoh')

%---------------------------------------------------------------------'Pulsar una tecla para continuar...'
pause;
'---------------------------------------------------------------------' 'Controlador P en forma discreta:'
%'Producto Gm por Gp:'
GmGcp_z = Gm_z * Kp

% Trazado LR
figure(1)
rlocus(GmGcp_z)
title('Lugar de Raíces del sistema con comp. P') axis([-1.1,1.1,-1.1,1.1])

%---------------------------------------------------------------------figure(2)
bode(GmGcp_z)
title('Bode del sistema con comp. P')
grid

%---------------------------------------------------------------------'Función de transferencia a lazo cerrado T(z) con comp. P:' T = Gm_z*Kp/(1+Gm_z*Kp)
% Respuesta al escalón discretizada
figure(3)
step(T,20)
grid
xlabel('Tiempo (segundos)')
ylabel('Posición angular(rad)')
title('Respuesta del Sistema con comp. P') %---------------------------------------------------------------------% Respuesta a la rampa discretizada.
figure(4)
t = [0:Ts:10]';
rampa = t;
lsim(T,rampa,t)
title('Tracking del MR08D-4 con comp. P a velocidad angular de 1rad/seg') ylabel('Rampa de 1rad/seg')
xlabel('Tiempo')
grid

%---------------------------------------------------------------------% Ubicación polos y ceros en plano Z
figure(5)
pzmap(T)

%---------------------------------------------------------------------'Pulsar una tecla para continuar...'
pause;
'---------------------------------------------------------------------' 'Controlador PI en forma discreta:'
Gcpi_z = Kp*tf([1+Ki*Ts -1],[1 -1],Ts)

%---------------------------------------------------------------------'Producto Gm por Gpi:'
GmGcpi_z = Gm_z * Gcpi_z

% Trazado LR
figure(1)
rlocus(GmGcpi_z)
title('Lugar de Raíces del sistema con comp. PI') axis([-1.1,1.1,-1.1,1.1])

%---------------------------------------------------------------------figure(2)
bode(GmGcpi_z)

title('Bode del sistema con comp. PI')
grid

%---------------------------------------------------------------------'Función de transferencia a lazo cerrado T(z) con comp. PI:' T = Gm_z*Gcpi_z/(1+Gm_z*Gcpi_z)
% Respuesta al escalón discretizada
figure(3)
step(T,20)
grid
xlabel('Tiempo (segundos)')
ylabel('Posición (rad)')
title('Respuesta escalonada del Sistema con comp. PI')

%---------------------------------------------------------------------% Respuesta a la rampa discretizada.
figure(4)
t = [0:Ts:10]';
rampa = t;
lsim(T,rampa,t)
title('Tracking del MR08D-4 con comp. PI a velocidad angular de 1rad/seg') ylabel('Rampa de 1rad/seg')
xlabel('Tiempo')
grid

%---------------------------------------------------------------------% Ubicación polos y ceros en plano Z
figure(5)
pzmap(T)
%---------------------------------------------------------------------'Pulsar una tecla para continuar...'
pause;
'---------------------------------------------------------------------' 'Controlador PID en forma discreta:'
Gcpid_z = Kp*tf([1+Ki*Ts+Kd/Ts -1-2*Kd/Ts Kd/Ts],[1 -1 0],Ts)

%---------------------------------------------------------------------
'Producto Gm por Gpid:'
GmGcpid_z = Gm_z * Gcpid_z

% Trazado LR
figure(1)
rlocus(GmGcpid_z)
title('Lugar de Raíces del sistema con comp. PID') axis([-1.1,1.1,-1.1,1.1])
%---------------------------------------------------------------------

figure(2)
bode(GmGcpid_z)
title('Bode del sistema con comp. PID')
grid
%---------------------------------------------------------------------'Función de transferencia a lazo cerrado T(z) con comp. PID:' T = Gm_z*Gcpid_z/(1+Gm_z*Gcpid_z)
zpk(T)
% Respuesta al escalón discretizada
figure(3)
step(T,20)
grid
xlabel('Tiempo (segundos)')
ylabel('Posición (rad)')
title('Respuesta escalonada del Sistema con comp. PID')

%---------------------------------------------------------------------
% Respuesta a la rampa discretizada.
figure(4)
t = [0:Ts:10]';
rampa = t;
lsim(T,rampa,t)
title('Tracking del MR08D-4 con comp. PID velocidad angular de 1rad/seg') ylabel('Rampa de 1rad/seg')
xlabel('Tiempo')
grid

%---------------------------------------------------------------------% Ubicación polos y ceros en plano Z
figure(5)
pzmap(T)

%---------------------------------------------------------------------% Ceros, polos y ganancia de T(z).
[zT,pT,kT] = zpkdata(T,'v')
Cuya salida al Command Window es:

Función de transferencia del motor Gm(s) en forma analógica:

( )

( )
( )
= | =
E s

s
G s

a

m
m

θ

293.3
------------------------------------s^3 + 237.8 s^2 + 8856 s

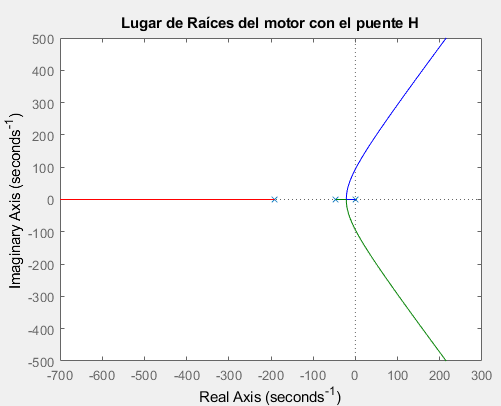
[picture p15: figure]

Figura Nº7.2. Lugar de raíces del motor y puente H en plano s

--------------------------------------------------------------------Período de muestreo:
Ts =
0.0160

Constante integrativa:
Ki =
0.5

Constante proporcional:
Kp =
50

Constante derivativa
Kd =
0.01

--------------------------------------------------------------------Función de transferencia del motor Gm(z)discreta:

( )

( )
( )
= | =
E z

z
G z

a

m
m

θ

8.874e-05 z^2 + 0.0001616 z + 1.38e-05 --------------------------------------------------------z^3 - 1.524 z^2 + 0.5462 z - 0.02227

Pulsar una tecla para continuar...

---------------------------------------------------------------------Controlador P en forma discreta:

GcP (z) =

0.004437 z^2 + 0.008079 z + 0.0006898 --------------------------------------------------------z^3 - 1.524 z^2 + 0.5462 z - 0.02227

Figura N°7.3: Lugar de raíces en Plano z con controlador P

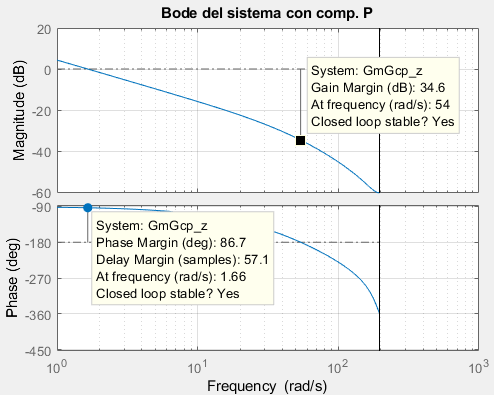
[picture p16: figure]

Figura Nº7.4: Diagrama de Bode y determinación de márgenes de ganancia y fase

Función de transferencia a lazo cerrado T(z) con comp. P:

( )

( ) ( )
( ) ( )

=
+

=
G | z G z
G | z G z
T z
cP | m
cP | m
m
1 | .

0.004437 z^5 + 0.001317 z^4 - 0.009198 z^3 + 0.003262 z^2 + 0.0001968 z - 1.536e-05 -----------------------------------------------------------------------------------------------------------------------z^6 - 3.043 z^5 + 3.416 z^4 - 1.718 z^3 + 0.3694 z^2 - 0.02413 z + 0.0004805

Figura Nº7.5: Respuesta al escalón del controlador P

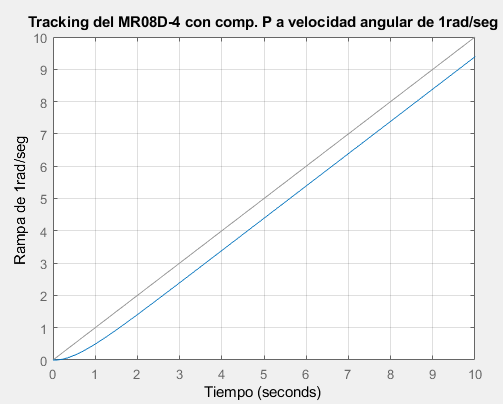
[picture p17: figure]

Figura Nº7.6: Respuesta a la rampa del Controlador P. Presenta error permanente

Figura Nº7.7: Constelación de polos y ceros en plano z del controlador P

Pulsar una tecla para continuar... ---------------------------------------------------------------------

Controlador PI en forma discreta:

GcPI (z) =

50.4 z - 50
z - 1
Producto Gm por Gpi:

GcPI (z).Gm

(z) =

0.004472 z^3 + 0.003707 z^2 - 0.007384 z - 0.0006898 ---------------------------------------------------------------------------z^4 - 2.524 z^3 + 2.07 z^2 - 0.5684 z + 0.02227

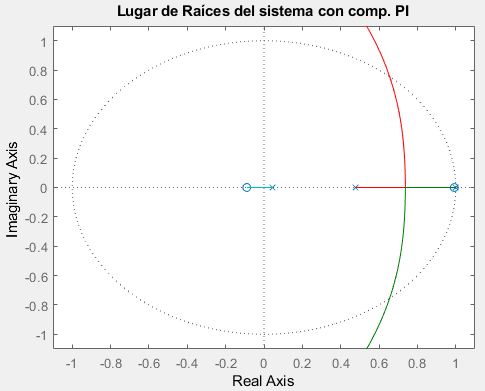
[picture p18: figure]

Figura Nº7.8. Lugar de raíces de controlador PI en plano z

Figura Nº7.9: Diagrama de Bode y determinación de márgenes de ganancia y fase

Función de transferencia a lazo cerrado T(z) con comp. PI:

( )

( ) ( )
( ) ( )

=
+

=
G | z G z
G | z G z
T z
cPI | m
cPI | m
m
1 | .

0.004472 z^7 - 0.007581 z^6 - 0.00748 z^5 + 0.02308 z^4 - 0.01555 z^3 + 0.002852 z^2 + 0.0002277 z - 1.536e-05 ------------------------------------------------------------------------------------------------------------------------------------------------------------z^8 - 5.043 z^7 + 10.5 z^6 - 11.59 z^5 + 7.222 z^4 - 2.481 z^3 + 0.4182 z^2 - 0.02509 z + 0.0004805

Figura Nº7.10: Respuesta al escalón del controlador PI: Presenta sobrepico

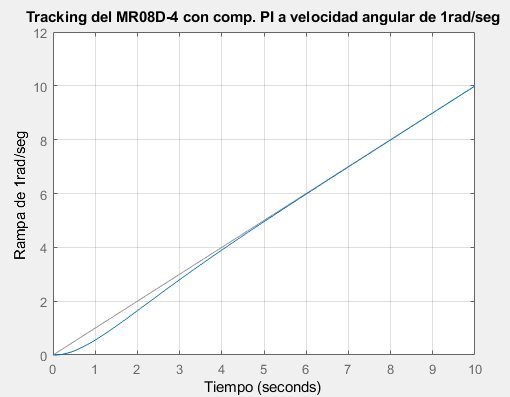
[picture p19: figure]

Figura Nº7.11: Respuesta a la rampa del Controlador PI. No presenta error permanente

Figura Nº7.12: Constelación de polos y ceros en plano z del controlador PI

Pulsar una tecla para continuar... ---------------------------------------------------------------------Controlador PID en forma discreta:

GcPID (z) =

0.007246 z^4 + 0.00321 z^3 - 0.01428 z^2 + 0.003497 z + 0.0004311 ----------------------------------------------------------------------------------------------z^5 - 2.524 z^4 + 2.07 z^3 - 0.5684 z^2 + 0.02227 z

Producto Gm por Gpid:

GcPID (z).Gm

(z) =

0.007246 z^9 - 0.01508 z^8 - 0.00738 z^7 + 0.04206 z^6 - 0.03962 z^5 + 0.01434 z^4 - 0.001414 z^3 - 0.0001672 z^2 + 9.6e-06 z -------------------------------------------------------------------------------------------------------------------------------------------------------------
z^10 - 5.041 z^9 + 10.5 z^8 - 11.59 z^7 + 7.241 z^6 - 2.505 z^5 + 0.4296 z^4 - 0.02673 z^3 + 0.0003287 z^2 + 9.6e-06 z

Figura Nº7.13: Lugar de raíces de controlador PID en plano z

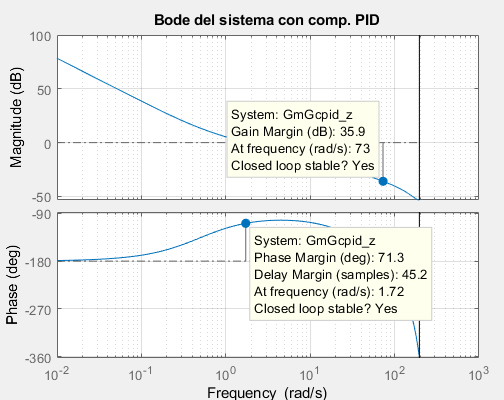
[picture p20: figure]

Figura Nº7.14: Diagrama de Bode y determinación de márgenes de ganancia y fase

Función de transferencia a lazo cerrado T(z) con comp. PID:

( )

( ) ( )
( ) ( )

=
+

=
G | z G z
G | z G z
T z
cPID | m
cPID | m
m
1 | .

0.0881 z^9 - 0.3197 z^8 + 0.3018 z^7 + 0.2282 z^6 - 0.6186 z^5 + 0.4148 z^4 - 0.09362 z^3 - 0.0008435 z^2 + 5.676e-010 z -----------------------------------------------------------------------------------------------------------------------------------------------------------------z^10 - 5.745 z^9 + 13.85 z^8 - 18.06 z^7 + 13.6 z^6 - 5.813 z^5 + 1.255 z^4 - 0.09362 z^3 - 0.0008435 z^2 + 5.676e-010 z

Forma ceros, polos y ganancia

( )

( ) ( )
( ) ( )

=
+

=
G | z G z
G | z G z
T z
cPID | m
cPID | m
m
1 | .

0.0072456 z (z+1.731) (z-1)^2 (z-0.992) (z-0.4772) (z-0.3858) (z+0.08981) (z-0.04666) --------------------------------------------------------------------------------------------------------------------------------z (z-1) (z-1) (z-0.4855) (z-0.4772) (z-0.0711) (z-0.04666) (z+0.01283) (z^2 - 1.973z + 0.9731)

Figura Nº7.15: Respuesta al escalón del controlador PID.

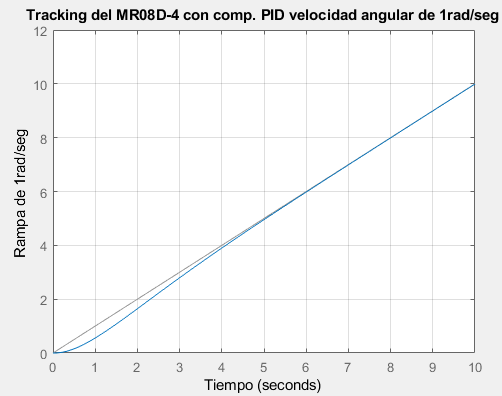
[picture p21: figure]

Figura Nº7.16: Respuesta a la rampa del Controlador PID.

Figura Nº7.17: Constelación de polos y ceros en plano z del controlador PID

(Ceros de T(z)) zT =
0
-1.7310 + 0.0000i
1.0000 + 0.0000i
1.0000 - 0.0000i
0.9920 + 0.0000i
0.4772 + 0.0000i
0.3858 + 0.0000i
-0.0898 + 0.0000i
0.0467 + 0.0000i
-1.2448
0.9830 + 0.0346i
0.9830 - 0.0346i
1.0000
1.0000
0.9167
-0.0087
0.0000

(Polos de T(z)) pT =
0
1.0000 + 0.0000i
1.0000 + 0.0000i
0.9864 + 0.0059i
0.9864 - 0.0059i
0.4855 + 0.0000i
0.4772 + 0.0000i
0.0711 + 0.0000i
0.0467 + 0.0000i
-0.0128 + 0.0000i

(Ganancia de T(z)) kT =

0.0072

### 7.5.2. Conclusiones de la simulación

- En el caso del controlador P, en la figura Nº 7.5, se tiene una respuesta al escalón sobreamortiguada con error permanente nulo, pero en la figura Nº 7.6, en la respuesta a la rampa, hay un error permanente dentro de
seg

rad 0,5
, esto indica que el sistema es de tipo 1

(un polo en el origen en el plano s o en uno en el plano z), y para que tenga error permanente nulo a la respuesta a la rampa, hay que incorporar el compensador PI.

- En el caso del controlador PI, en la figura Nº7.10, se tiene una respuesta al escalón con un sobrepico porcentual de 15% con error permanente nulo, pero en la figura Nº7.11, en la respuesta a la rampa, no hay error permanente, esto indica que el sistema ahora es de tipo 2 (dos polos en el origen en el plano s o en uno en el plano z), Observando el Bode de la figura Nº7.9, el sistema presenta un margen de fase de 70,5º.
- En el caso del controlador PID, en la figura Nº7.15, se tiene una respuesta al escalón con un sobrepico porcentual de 14% con error permanente nulo, en la figura Nº7.16, en la respuesta a la rampa, no hay error permanente.
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

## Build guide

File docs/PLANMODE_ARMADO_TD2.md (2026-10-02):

# Planmode TD2 - Armado y Puesta en Marcha Sun Tracker ESP32

Estado: plan operativo para ejecucion por etapas.  
Enfoque: prolijo, trazable y con validaciones tempranas.

## 1. Principio de trabajo

Objetivo: llegar a un sistema funcional por incrementos, evitando cableados grandes
sin validacion previa.

Regla: cada etapa cierra con evidencia medible antes de pasar a la siguiente.

## 2. Roadmap visual

```mermaid
flowchart LR
  P0[Etapa 0
  Baseline y seguridad] --> P1[Etapa 1
  ESP32 + ADC x4]
  P1 --> P2[Etapa 2
  PI en lazo abierto]
  P2 --> P3[Etapa 3
  Driver potencia en banco]
  P3 --> P4[Etapa 4
  Integracion mecanica]
  P4 --> P5[Etapa 5
  Calibracion y cierre]
```

## 3. Etapas detalladas

## Etapa 0 - Baseline y seguridad

Entregable:

- Banco ordenado, alimentacion definida, masas etiquetadas, plan de apagado.

Checklist:

- [ ] Separar alimentacion logica y potencia.
- [ ] Definir punto unico de GND comun.
- [ ] Incorporar fusible de entrada de potencia.
- [ ] Definir boton de paro rapido (al menos corte de EN del puente H).

Criterio de salida:

- Encendido/apagado seguro repetible sin reset espurio del ESP32.

## Etapa 1 - ESP32 + sensores LDR

Entregable:

- Lectura estable de F0-F1-F2-F3 por serial.

Checklist:

- [ ] Configurar ADC1 en 4 canales.
- [ ] Muestreo periodico a dt fijo (ej. 20 ms).
- [ ] Filtro simple (media movil corta).
- [ ] Identificar offset y rango util por canal.

Criterio de salida:

- Variacion coherente de canales al sombrear cada LDR por separado.

## Etapa 2 - Control PI en lazo abierto

Entregable:

- Calculo online de `errAz`, `errEl`, integradores y comandos `uAz/uEl` sin mover motores.

Checklist:

- [ ] Portar formulas de error del firmware AVR.
- [ ] Portar PI con anti-windup (`Reset_aw`).
- [ ] Saturacion de salida.
- [ ] Zona muerta configurable.

Criterio de salida:

- Telemetria serial estable y sin windup creciente ante error sostenido.

## Etapa 3 - Potencia en banco (sin estructura mecanica)

Entregable:

- PWM + direccion controlando ambos canales del puente H con carga de prueba.

Checklist:

- [ ] Verificar niveles logicos ESP32 a entradas del puente H.
- [ ] Probar cada eje por separado.
- [ ] Verificar que `DIR` invierte sentido real.
- [ ] Medir temperatura del driver en 10 min de prueba.

Criterio de salida:

- Control bidireccional estable sin sobrecalentamiento ni resets del ESP32.

## Etapa 4 - Integracion mecanica real

Entregable:

- Tracker moviendo azimut y elevacion con feedback LDR.

Checklist:

- [ ] Conectar motores reales y verificar consumo.
- [ ] Definir limites mecanicos.
- [ ] Implementar parada por timeout de movimiento.
- [ ] Verificar sentido correcto de cada eje respecto al error.

Criterio de salida:

- El sistema reduce error en ambos ejes desde posiciones iniciales distintas.

## Etapa 5 - Calibracion y cierre TD2

Entregable:

- Parametros finales, evidencias de prueba y version candidata de entrega.

Checklist:

- [ ] Ajuste fino de `Kp/Ki` por eje.
- [ ] Registro de estabilidad (sin oscilacion sostenida).
- [ ] Tabla final de pines y conexiones.
- [ ] Documentacion de seguridad y operacion.

Criterio de salida:

- Repetibilidad en 3 ciclos completos de prueba.

## 4. Vista de componentes del armado

```mermaid
flowchart TB
  subgraph LOGICA[Dominio de logica]
    USB[USB 5V]
    REG33[Regulacion 3.3V ESP32]
    ESP[ESP32 DevKit]
    SENS[Modulo LDR x4]
  end

  subgraph POT[Dominio de potencia]
    VIN[Fuente motor 9-12V]
    HB[Puente H doble]
    M1[Motor Azimut]
    M2[Motor Elevacion]
  end

  USB --> REG33 --> ESP
  SENS --> ESP
  ESP --> HB
  VIN --> HB
  HB --> M1
  HB --> M2
```

## 5. Riesgos abiertos (por datos aun no definidos)

| Riesgo | Impacto | Mitigacion provisional |
|---|---|---|
| Puente H final no definido | Re-trabajo de pines y protecciones | Diseñar HAL de salidas desacoplada |
| Tension real de motor incierta | Sobrecalentamiento o bajo torque | Arrancar con fuente limitada y medir |
| Sin finales de carrera confirmados | Riesgo mecanico | Agregar timeout + parada manual |
| Corriente de arranque desconocida | Riesgo de danio en driver | Medicion previa con pinza o shunt |

## 6. Definition of Done (TD2)

- Firmware ESP32 controla dos ejes con PI estable.
- Cableado final documentado y etiquetado.
- Pruebas de seguridad ejecutadas y registradas.
- Documento tecnico de TD2 actualizado con valores finales reales.

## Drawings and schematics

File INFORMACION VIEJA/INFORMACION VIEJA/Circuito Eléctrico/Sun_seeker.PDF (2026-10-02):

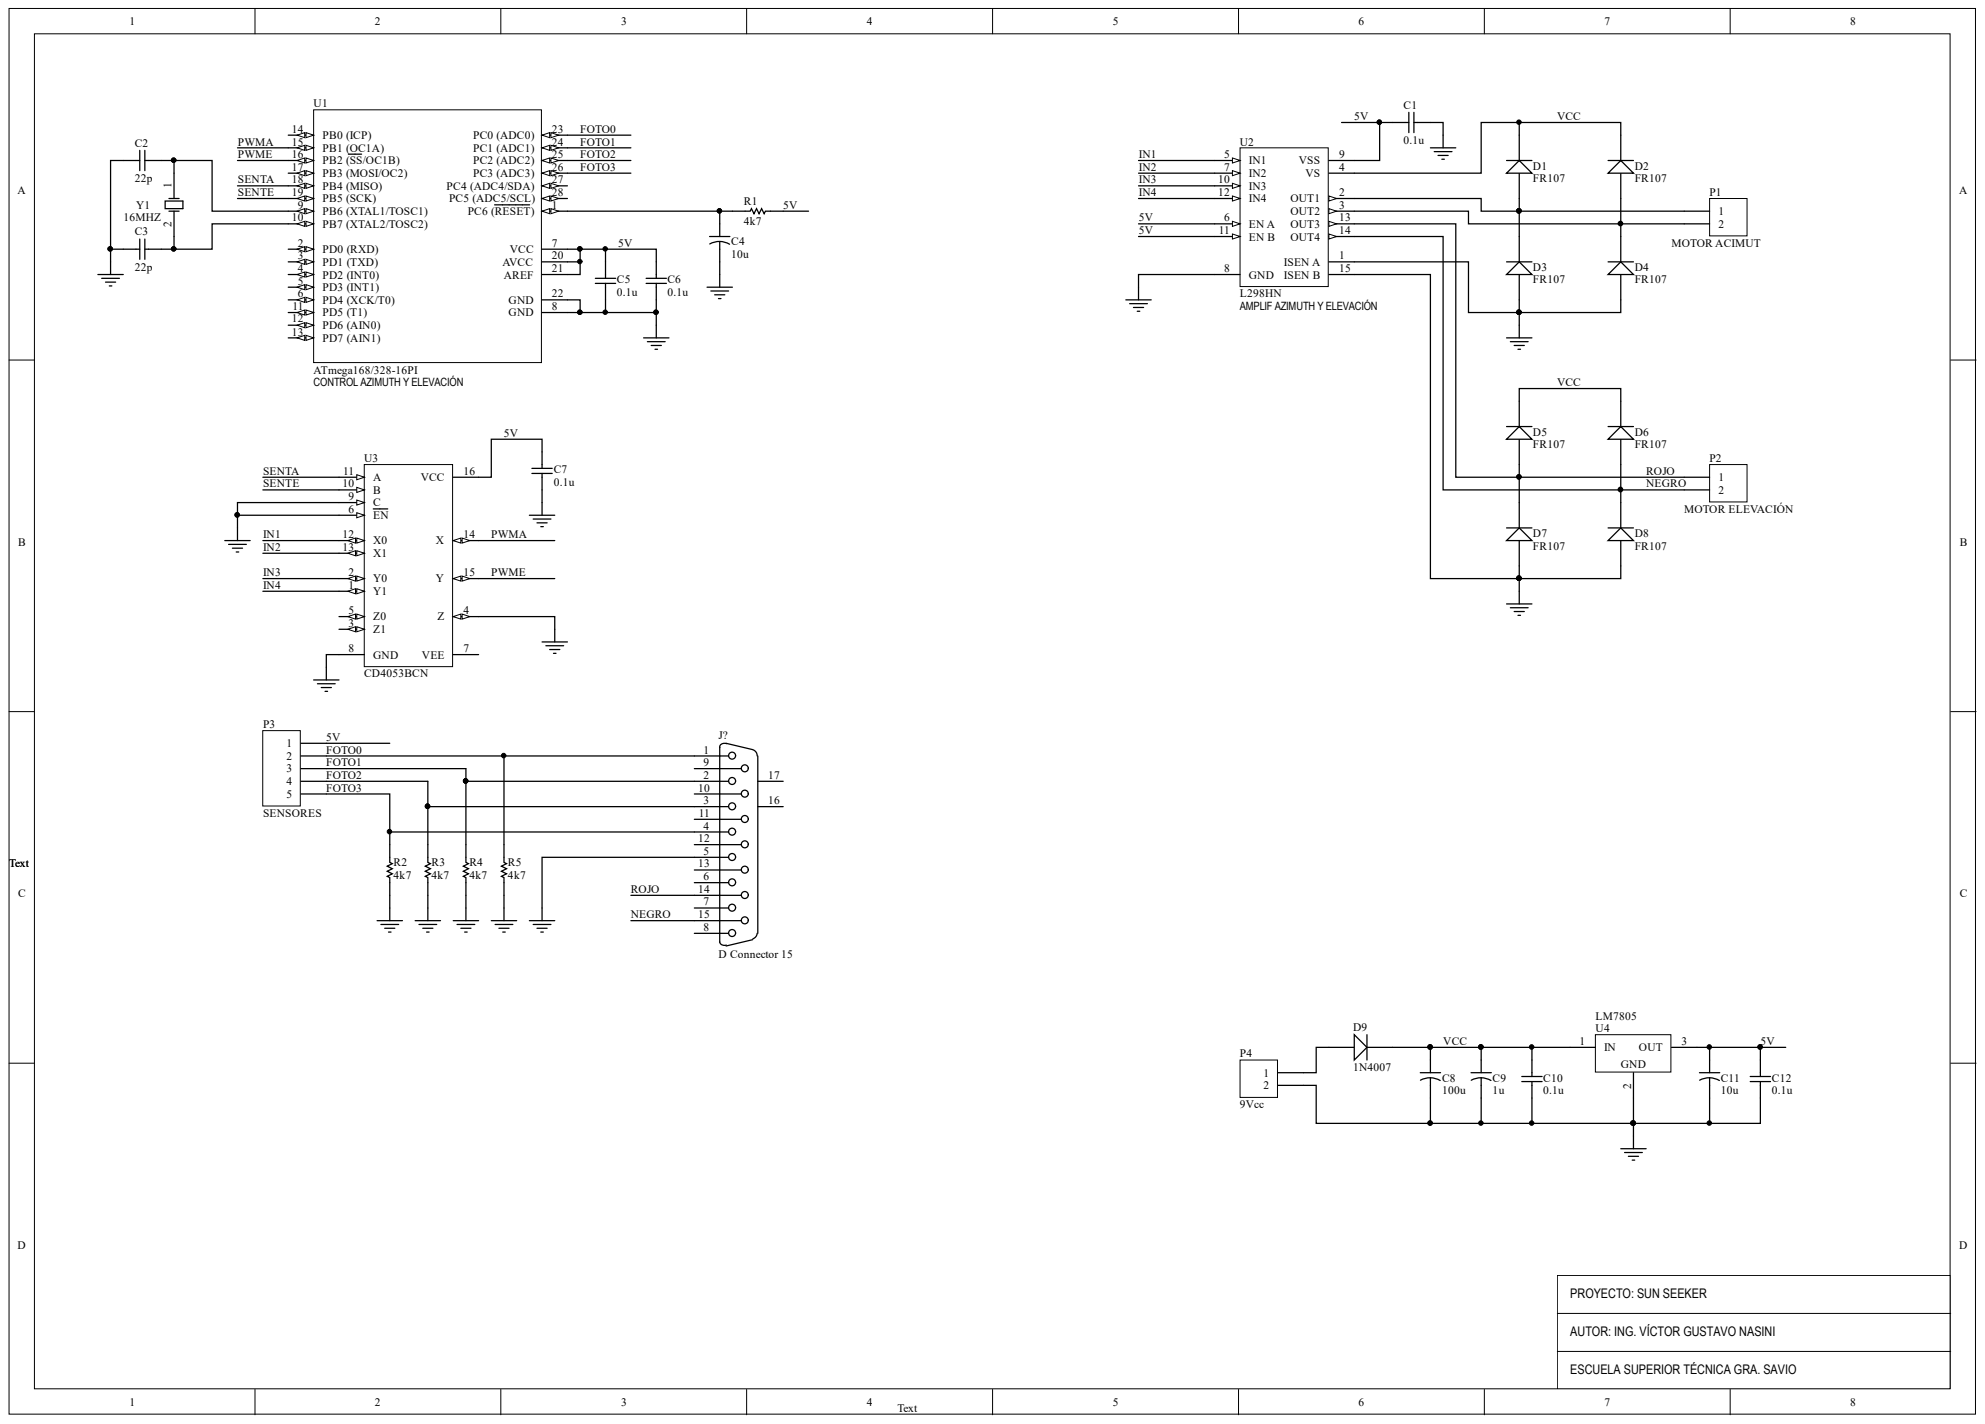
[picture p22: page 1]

AUTOR: ING. VÍCTOR GUSTAVO NASINI

ESCUELA SUPERIOR TÉCNICA GRA. SAVIO

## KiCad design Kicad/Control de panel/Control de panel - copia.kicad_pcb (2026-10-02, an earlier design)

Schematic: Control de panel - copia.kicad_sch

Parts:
C1, C4, C5: 0.1u; C_Disc_D6.0mm_W2.5mm_P5.00mm
C2: 1u; CP_Radial_D6.3mm_P2.50mm
C3: 10u; CP_Radial_D6.3mm_P2.50mm
C6: 100u; CP_Radial_D6.3mm_P2.50mm
D1, D2, D3, D4, D5, D6, D7, D8, D10: 1N5822; D_DO-201AD_P15.24mm_Horizontal
J1: Output MOTORA; TerminalBlock_Phoenix_PT-1,5-2-5.0-H_1x02_P5.00mm_Horizontal
J2: Output MOTORB; TerminalBlock_Phoenix_PT-1,5-2-5.0-H_1x02_P5.00mm_Horizontal
J5: Input 9v; TerminalBlock_Phoenix_PT-1,5-2-5.0-H_1x02_P5.00mm_Horizontal
J8: Conn_01x05_Pin; PinHeader_1x05_P2.00mm_Vertical
R1, R2, R3, R4: 4k7; R_Axial_DIN0207_L6.3mm_D2.5mm_P10.16mm_Horizontal
R5, R6, R7, R8, R9, R10, R11, R12: R; R_Axial_DIN0207_L6.3mm_D2.5mm_P10.16mm_Horizontal
U1: L298N; TO-220-15_P2.54x5.08mm_StaggerOdd_Lead4.58mm_Vertical
U2: LM7805_TO220; TO-220-3_Vertical
U4: DEVKIT_V1_ESP32-WROOM-32; MODULE_DEVKIT_V1_ESP32-WROOM-32; PARTREV N/A
U5: CNY74-4H; DIL16; MPN CNY74-4H
U6: ESP32_DEVKIT_V1_30PIN

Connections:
/Vcc 5v: C1.1, C3.1, C5.1, U1.6 (EnA), U1.9 (Vss), U1.11 (EnB), U2.3 (VO), U4.19 (EXT_5V), U5.10, U5.11, U5.14, U5.15
GND: C1.2, C2.2, C3.2, C4.2, C5.2, C6.2, D3.2 (A), D4.2 (A), D5.2 (A), D7.2 (A), J5.1, R1.2, R2.2, R3.2, R4.2, R5.1, R6.2, R7.2, R8.2, U1.1 (SENSE_A), U1.8 (GND), U1.15 (SENSE_B), U2.2 (GND), U4.14 (GND1), U4.32 (GND2), U5.3, U5.6, U5.7
unnamed: D1.2 (A), D4.1 (K), J1.1, U1.2 (OUT1)
unnamed: C2.1, C4.1, C6.1, D1.1 (K), D2.1 (K), D6.1 (K), D8.1 (K), D10.1 (K), U1.4 (Vs), U2.1 (VI)
unnamed: D2.2 (A), D3.1 (K), J1.2, U1.3 (OUT2)
unnamed: D5.1 (K), D6.2 (A), J2.2, U1.13 (OUT3)
unnamed: D7.1 (K), D8.2 (A), J2.1, U1.14 (OUT4)
unnamed: D10.2 (A), J5.2
unnamed: J8.1, U4.1 (3V3)
unnamed: J8.2, R4.1, U4.6 (IO35)
unnamed: J8.3, R3.1, U4.5 (IO34)
unnamed: J8.4, R2.1, U4.4 (SENSOR_VN)
unnamed: J8.5, R1.1, U4.3 (SENSOR_VP)
unnamed: R9.1, U5.1
unnamed: R10.1, U5.4
unnamed: R11.1, U5.5
unnamed: R12.1, U5.8
unnamed: R8.1, U1.5 (IN1), U5.9
unnamed: R7.1, U1.7 (IN2), U5.12
unnamed: R6.1, U1.10 (IN3), U5.13
unnamed: R5.2, U1.12 (IN4), U5.16
unnamed: R12.2, U4.27 (IO16)
unnamed: R11.2, U4.28 (IO17)
unnamed: R10.2, U4.30 (IO18)
unnamed: R9.2, U4.31 (IO19)

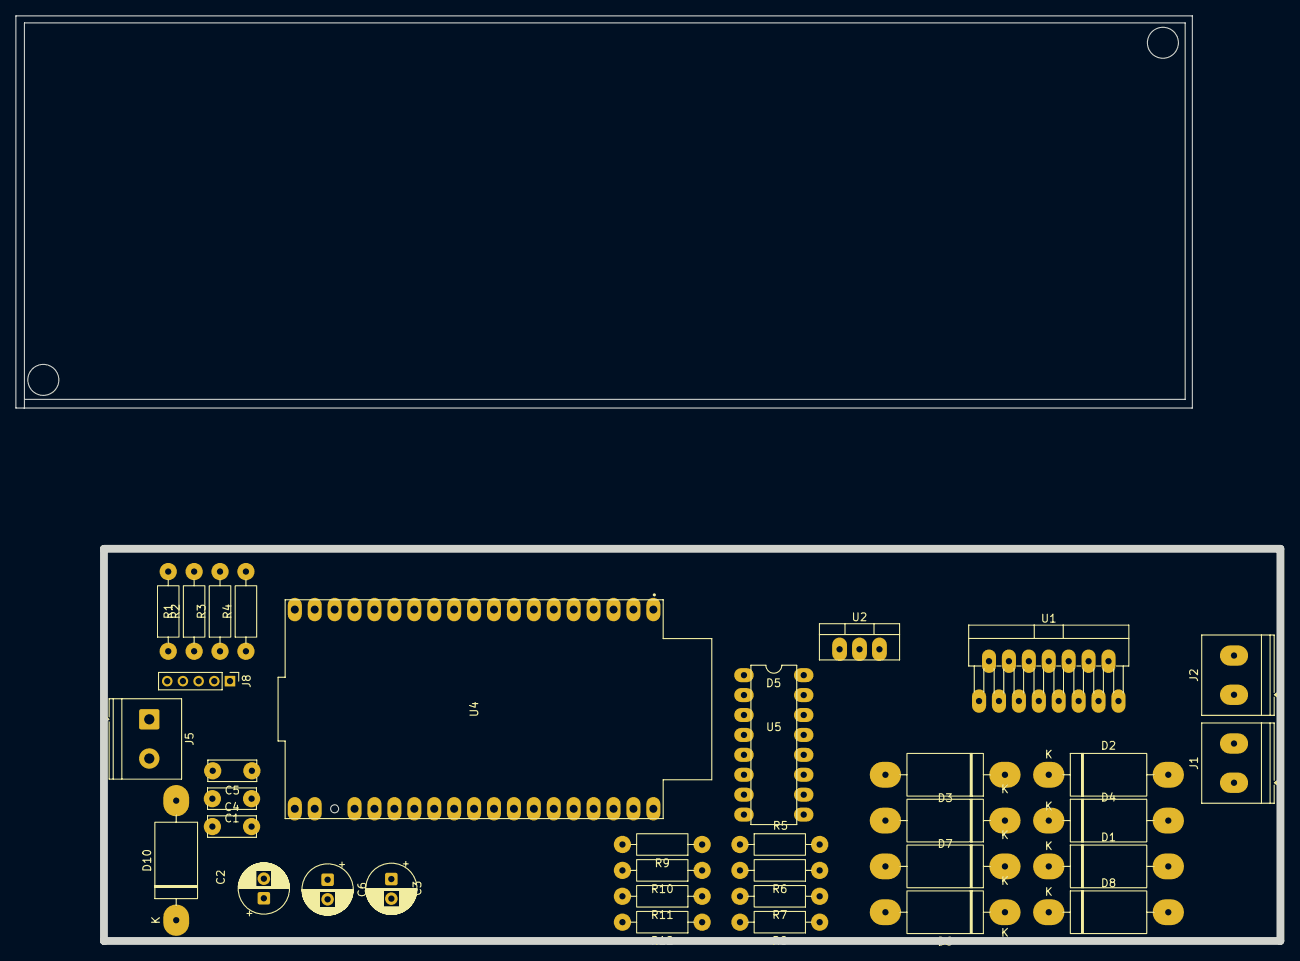
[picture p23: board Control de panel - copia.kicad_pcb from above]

Board: 2 copper layers, 150.0 x 50.0 mm, 35 parts (0 on the bottom side), 25 nets, no tracks yet.

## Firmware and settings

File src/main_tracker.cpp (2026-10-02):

/**
 * @file    main_tracker.cpp
 * @brief   Sun Tracker ESP32 — Tecnicas Digitales 2
 * @details Migra el controlador PI del firmware AVR (ATmega168/328, popo.c) a
 *          ESP32 DevKit V1 con PlatformIO/Arduino.
 *
 * Fuente original: INFORMACION VIEJA/.../popo/popo/{PID_Azim.c, PID_Elev.c,
 *                  Leo_Fotos.c, Constantes.c, PWM.c, PORT.c}
 *
 * Mapeo AVR -> ESP32
 * ------------------
 *   ADC0 (FOTO0) -> GPIO36   ADC0 (FOTO1) -> GPIO39
 *   ADC2 (FOTO2) -> GPIO34   ADC3 (FOTO3) -> GPIO35
 *   OC1A / PB1  -> GPIO25   (LEDC CH0 — PWM azimut)
 *   OC1B / PB2  -> GPIO26   (LEDC CH1 — PWM elevacion)
 *   PB4         -> GPIO27   (sentido azimut)
 *   PB5         -> GPIO14   (sentido elevacion)
 *
 * Datos de hardware faltantes (ver docs/PLANMODE_ARMADO_TD2.md):
 *   - Puente H final no definido  → ajustar pines ENA/ENB/IN segun driver
 *   - Tension real de motores     → se asume 9-12V, verificar en banco
 *   - Finales de carrera          → descomentar FAULT si se conectan
 *
 * @date 2026-06-09
 */

#include <Arduino.h>

// ============================================================================
// PINES — ESP32 DOIT DevKit V1
// ============================================================================

// Sensores (ADC1, entrada analog. solo lectura — NO usar WiFi simultaneamente)
constexpr int PIN_F0 = 36;   // ADC1_CH0 — LDR Foto0
constexpr int PIN_F1 = 39;   // ADC1_CH3 — LDR Foto1
constexpr int PIN_F2 = 34;   // ADC1_CH6 — LDR Foto2
constexpr int PIN_F3 = 35;   // ADC1_CH7 — LDR Foto3

// Salidas de control al puente H
constexpr int PIN_PWM_AZ = 25;   // ENA  — PWM azimut   (LEDC CH0)
constexpr int PIN_PWM_EL = 26;   // ENB  — PWM elevacion (LEDC CH1)
constexpr int PIN_DIR_AZ = 27;   // IN_A — sentido azimut
constexpr int PIN_DIR_EL = 14;   // IN_B — sentido elevacion

// Debug
constexpr int PIN_STATUS = 2;    // LED integrado — heartbeat

// ============================================================================
// LEDC (PWM hardware)
// ============================================================================
constexpr uint8_t  LEDC_CH_AZ    = 0;
constexpr uint8_t  LEDC_CH_EL    = 1;
constexpr uint32_t LEDC_FREQ_HZ  = 1000;   // 1 kHz — compatible con L298/L298N
constexpr uint8_t  LEDC_RES_BITS = 10;     // 10 bits → 0..1023 (igual que AVR)
constexpr int      PWM_MAX       = (1 << LEDC_RES_BITS) - 1;  // 1023

// ============================================================================
// PARAMETROS DE CONTROL — tomados literalmente de Constantes.c (AVR)
// ============================================================================
constexpr double KP_AZ    = 5.0;
constexpr double KI_AZ    = 0.1;
constexpr double KP_EL    = 5.0;
constexpr double KI_EL    = 0.1;
constexpr double RESET_AW = 400.0;   // limite anti-windup

// Zona muerta (nuevo respecto al AVR — evita oscilacion por ruido ADC)
constexpr int DEAD_BAND = 5;   // cuentas ADC en escala 10 bits

// Periodo de control
constexpr unsigned long DT_MS = 20;   // 20 ms ≈ 50 Hz

// ============================================================================
// ESTADO DEL CONTROLADOR
// ============================================================================
static double integral_Az = 0.0;
static double integral_El = 0.0;

// ============================================================================
// Lee canal ADC, promedia N muestras y convierte 12 bits → 10 bits
// (AVR usaba ADC de 10 bits; mantener escala para reutilizar constantes PI)
// ============================================================================
static int leerADC10(int pin, int n = 8) {
    long acum = 0;
    for (int i = 0; i < n; ++i) acum += analogRead(pin);
    return static_cast<int>((acum / n) >> 2);   // /4 para escalar 12→10 bits
}

// ============================================================================
// Detiene ambos motores de forma segura
// ============================================================================
static void pararMotores() {
    ledcWrite(LEDC_CH_AZ, 0);
    ledcWrite(LEDC_CH_EL, 0);
    integral_Az = 0.0;
    integral_El = 0.0;
}

// ============================================================================
// SETUP
// ============================================================================
void setup() {
    Serial.begin(115200);
    Serial.println();
    Serial.println("============================================");
    Serial.println(" TD2 — Sun Tracker ESP32  |  boot OK");
    Serial.println(" Kp=5.0  Ki=0.1  Reset_aw=400  dt=20ms");
    Serial.println("============================================");

    // Sentido y LED
    pinMode(PIN_DIR_AZ, OUTPUT);   digitalWrite(PIN_DIR_AZ, LOW);
    pinMode(PIN_DIR_EL, OUTPUT);   digitalWrite(PIN_DIR_EL, LOW);
    pinMode(PIN_STATUS, OUTPUT);   digitalWrite(PIN_STATUS, LOW);

    // ADC: resolucion 12 bits, atenuacion 11 dB (0..3.3 V)
    analogReadResolution(12);
    analogSetPinAttenuation(PIN_F0, ADC_11db);
    analogSetPinAttenuation(PIN_F1, ADC_11db);
    analogSetPinAttenuation(PIN_F2, ADC_11db);
    analogSetPinAttenuation(PIN_F3, ADC_11db);

    // LEDC PWM — canal azimut
    ledcSetup(LEDC_CH_AZ, LEDC_FREQ_HZ, LEDC_RES_BITS);
    ledcAttachPin(PIN_PWM_AZ, LEDC_CH_AZ);
    ledcWrite(LEDC_CH_AZ, 0);

    // LEDC PWM — canal elevacion
    ledcSetup(LEDC_CH_EL, LEDC_FREQ_HZ, LEDC_RES_BITS);
    ledcAttachPin(PIN_PWM_EL, LEDC_CH_EL);
    ledcWrite(LEDC_CH_EL, 0);

    Serial.println("[TD2] Entrando al loop de control...");
}

// ============================================================================
// LOOP DE CONTROL — dt fijo de DT_MS ms
// ============================================================================
void loop() {
    static unsigned long lastTick = 0;
    static uint32_t seq = 0;

    const unsigned long now = millis();
    if (now - lastTick < DT_MS) return;
    lastTick = now;
    ++seq;

    // -------------------------------------------------------------------------
    // 1. Lectura de sensores (Leo_Fotos.c portado)
    //    F0=ADC0, F1=ADC1, F2=ADC2, F3=ADC3 en escala 10 bits
    // -------------------------------------------------------------------------
    const int F0 = leerADC10(PIN_F0);
    const int F1 = leerADC10(PIN_F1);
    const int F2 = leerADC10(PIN_F2);
    const int F3 = leerADC10(PIN_F3);

    // Validacion basica de sensores (rango ADC: > 10 cuentas = sensor conectado)
    if (F0 < 10 && F1 < 10 && F2 < 10 && F3 < 10) {
        if (seq % 50 == 0)
            Serial.println("[FAULT] Sensores invalidos — motores detenidos");
        pararMotores();
        digitalWrite(PIN_STATUS, HIGH);   // LED fijo = fault
        return;
    }

    // -------------------------------------------------------------------------
    // 2. Calculo de error (formulas identicas al AVR — PID_Elev.c / PID_Azim.c)
    // -------------------------------------------------------------------------
    //   Elevacion: inferior (F2+F3) - superior (F0+F1)
    //   Azimut:    derecha  (F1+F3) - izquierda (F0+F2)
    const double Error_El = static_cast<double>(F2 + F3 - F0 - F1) / 2.0;
    const double Error_Az = static_cast<double>(F1 + F3 - F0 - F2) / 2.0;

    // -------------------------------------------------------------------------
    // 3. PI Elevacion (PID_Elev.c portado)
    //    Sentido AVR: PWM_El >= 0 → PB5=1 (set 0x20) → DIR_EL HIGH
    //                 PWM_El <  0 → PB5=0 (clr 0xDF) → DIR_EL LOW
    // -------------------------------------------------------------------------
    int  pwm_El = 0;
    bool dir_El = false;

    if (abs(Error_El) > DEAD_BAND) {
        integral_El += Error_El;
        if (integral_El >  RESET_AW) integral_El =  RESET_AW;
        if (integral_El < -RESET_AW) integral_El = -RESET_AW;

        double u_El = (Error_El * KP_EL) + (integral_El * KI_EL);
        int    raw  = static_cast<int>(u_El);

        if (raw >= 0) {
            dir_El = true;    // PORTB |= 0x20  (PB5 = 1)
        } else {
            dir_El = false;   // PORTB &= 0xDF  (PB5 = 0)
            raw = -raw;
        }
        pwm_El = constrain(raw, 0, PWM_MAX);
    } else {
        integral_El = 0.0;   // reset integrador en zona muerta
    }

    // -------------------------------------------------------------------------
    // 4. PI Azimut (PID_Azim.c portado)
    //    Sentido AVR: PWM_Az >= 0 → PB4=0 (clr 0xEF) → DIR_AZ LOW
    //                 PWM_Az <  0 → PB4=1 (set 0x10) → DIR_AZ HIGH
    // -------------------------------------------------------------------------
    int  pwm_Az = 0;
    bool dir_Az = false;

    if (abs(Error_Az) > DEAD_BAND) {
        integral_Az += Error_Az;
        if (integral_Az >  RESET_AW) integral_Az =  RESET_AW;
        if (integral_Az < -RESET_AW) integral_Az = -RESET_AW;

        double u_Az = (Error_Az * KP_AZ) + (integral_Az * KI_AZ);
        int    raw  = static_cast<int>(u_Az);

        if (raw >= 0) {
            dir_Az = false;   // PORTB &= 0xEF  (PB4 = 0)
        } else {
            dir_Az = true;    // PORTB |= 0x10  (PB4 = 1)
            raw = -raw;
        }
        pwm_Az = constrain(raw, 0, PWM_MAX);
    } else {
        integral_Az = 0.0;
    }

    // -------------------------------------------------------------------------
    // 5. Aplicar salidas al puente H
    // -------------------------------------------------------------------------
    digitalWrite(PIN_DIR_EL, dir_El ? HIGH : LOW);
    digitalWrite(PIN_DIR_AZ, dir_Az ? HIGH : LOW);
    ledcWrite(LEDC_CH_EL, pwm_El);
    ledcWrite(LEDC_CH_AZ, pwm_Az);

    // -------------------------------------------------------------------------
    // 6. Telemetria serial (cada 500 ms ≈ 25 ciclos a dt=20ms)
    // -------------------------------------------------------------------------
    if (seq % 25 == 0) {
        Serial.printf(
            "[%5lu] F0=%4d F1=%4d F2=%4d F3=%4d"
            " | eAz=%+6.1f eEl=%+6.1f"
            " | iAz=%+7.1f iEl=%+7.1f"
            " | pwmAz=%4d(%d) pwmEl=%4d(%d)\n",
            seq, F0, F1, F2, F3,
            Error_Az, Error_El,
            integral_Az, integral_El,
            pwm_Az, static_cast<int>(dir_Az),
            pwm_El, static_cast<int>(dir_El)
        );
    }

    // Heartbeat LED
    digitalWrite(PIN_STATUS, (seq % 50 < 25) ? HIGH : LOW);
}

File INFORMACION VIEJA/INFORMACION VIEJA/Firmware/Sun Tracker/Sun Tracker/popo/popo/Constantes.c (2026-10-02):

 
 // Canales del ADC
 adc_dato_0 = 0;
 adc_dato_1 = 0;
 adc_dato_2 = 0;
 adc_dato_3 = 0;
 
 Int_elev = 0;
 Int_azim = 0;

 error_elev = 0;
 error_azim = 0;



  
//===================================================
// ASIGNACIÓN DE VALORES A LAS CONSTANTES PARA EL PID
// --------------------------------------------------
   Integral_El = 0.0;
   Integral_Az = 0.0;

   // Ctes. PID
   Kp_El = 5.0;
   Ki_El = 0.1;
   Kd_El = 0.0;

   Kp_Az = 5.0;
   Ki_Az = 0.1;
   Kd_Az = 0.0;


    // Cte. reset anti-wind up
   //Reset_aw = 120.0;
   Reset_aw = 400.0;

  

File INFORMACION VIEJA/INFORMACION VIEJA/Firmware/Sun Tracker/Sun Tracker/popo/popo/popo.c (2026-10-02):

/************************************************************************************************/
/* CONTROL DE ELEVACIÓN Y AZIMUTH SUN TRACKER                                                   */
/* ------------------------------------------                                                   */
/* 28/01/2021                                                                                   */
/* Se actualiza el compilador a Atmel Studio 6.2 y el micro es ATMEL 328, compatible a 168.     */
/* Se sensan los movimientos de elevación y azimuth mediante LDRs.                              */
/* Foto 0: AIN0                                                                                 */
/* Foto 1: AIN1                                                                                 */
/* Foto 2: AIN2                                                                                 */
/* Foto 3: AIN3                                                                                 */
/* Movimiento Elevación: Prom foto0-1 - Prom Foto2-3                                            */
/* Movimiento Azimuth: Prom foto0-2 - Prom Foto1-3                                              */
/* El control de los motores es mediante PI, no es necesario PD porque el seguimiento es lento  */
/* Este programa está adaptado para el Sun Tracker con panel solar de SOLARTEC.                 */
/************************************************************************************************/

#include <avr/io.h>
#include <avr/signal.h>
#include <avr/interrupt.h>
#include <stdlib.h>
#include <math.h>
#include <avr/wdt.h>
#include "Def.h"
#include "PORT.c"
#include "ADC.c"
#include "USART.c"
#include "PWM.c"
#include "Leo_ADC.c"

/*************************************************************************************************/

int main(void)
{
	#include "Constantes.c"
	PORT_Init();
	ADC_Init();
	USART_Init();
	Fast_Pwm_Init();
		
	while(1)
	{
 	 // Subo bandera
	 PORTB |= 0x01;
	 // lee los 4 fototransistores
	 #include "Leo_fotos.c"
	 // Bajo bandera
	 PORTB &= 0xfe;
	 //-----------------------------------------------------
	 #include "PID_Elev.c"
	 #include "PID_Azim.c"
	}
}

//----------------------------------------------------------------------------------------

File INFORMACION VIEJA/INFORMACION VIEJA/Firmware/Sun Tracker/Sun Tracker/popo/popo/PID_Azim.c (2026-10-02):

      // PID
	  // ---  
      /* Determino control para movimiento azimuth */
      Error_Az = (adc_dato_1 + adc_dato_3 - adc_dato_0 - adc_dato_2) / 2;					 
					 
	  // Parte integrativa
	  Integral_Az = Error_Az + Integral_Az;

	  // Reset anti wind-up
	  if(Integral_Az >= Reset_aw)
 	     Integral_Az = Reset_aw;

	  if(Integral_Az <= -Reset_aw)
	     Integral_Az = -Reset_aw;
			
	  // Ley de contAzl
	  PID_Az = (Error_Az * Kp_Az) + (Integral_Az * Ki_Az);
	  PWM_Az = (int)(PID_Az);
			
	  // Determino sentido
	  if(PWM_Az >= 0)
	     // avanza paun lao
	   	 // Ley_pid es +
	     PORTB &= 0xef;		
  	  else
	  	{
		 // avanza pal otAz
	     PORTB |= 0x10;				 			 
	     // Ley_pid es -
		 PWM_Az = -1 * PWM_Az;
		}

	  // Limito el máximo y mínimo ley pid
	  if(PWM_Az >= 1023)
	  	 PWM_Az = 1023;
			
	  if(PWM_Az <= 0)
	     PWM_Az = 0;
			
	  // Waiting when an OCF1A completes.
	  while( !(TIFR1 & (1<<OCF1A)) )
	            ;
	  /* Saco el PWM para el motor Azll */
	  OCR1A = PWM_Az;
   
      /* OCF1A = OCF1B = 1 los limpio */
      TIFR1 |= 0x18;

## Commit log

2026-10-02 feat: migracion Sun Tracker a ESP32 para TD2, firmware de control y PCB KiCad
    [Control de panel - copia.kicad_pcb, Control de panel - copia.kicad_sch, Control de panel.kicad_pcb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]
2026-10-14 feat(firmware): refactorizar control PI con maquina de estados y reorganizar estructura del repositorio
    Firmware:
    - include/config.h centraliza pines, LEDC, ganancias PI, tiempos y umbrales
    - Maquina de estados TRACKING / NIGHT / SENSOR_FAULT con histeresis
    - Tiempo muerto de 40 ms antes de invertir el giro de un motor
    - ADC calibrado (analogReadMilliVolts) reescalado a 10 bits
    - Planificador millis() sin deriva, contador de overruns y loop WDT
    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
